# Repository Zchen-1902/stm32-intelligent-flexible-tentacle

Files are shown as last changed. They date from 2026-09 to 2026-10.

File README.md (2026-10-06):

# 基于示教学习的多触手智能柔性末端执行器

本项目面向柔性抓取与仿生作业场景，采用 STM32H743 作为主控制器、STM32G474 作为三电机 FOC 从控制器，集成 VL53L8CH ToF 感知、端侧 CNN/TCN 推理、CAN/FDCAN 通信、上位机控制与示教数据采集功能。

## 目录结构

```text
firmware/
  g4-motor-controller/   STM32G474 三电机 FOC 控制工程
  h7-main-controller/    STM32H743 感知、推理和多触手控制工程
pc/
  tentacle-controller/   多触手运动控制上位机
  act-data-collector/    ACT 示教数据采集上位机
training/
  gesture-cnn/           手势识别 CNN 训练代码
  act-tcn/               ACT/TCN 策略训练与 ONNX 导出代码
models/                  最终部署模型
hardware/                嘉立创 EDA 专业版 PCB 工程
docs/                    项目文档
```

## 主要功能

- STM32H743 完成 ToF 数据采集、模型推理、控制调度和状态管理。
- STM32G474 完成三台无刷电机的编码器读取、FOC 控制和安全保护。
- 主从控制器通过 CAN/FDCAN 交换目标位置与电机状态。
- 上位机支持单触手、双触手和四触手控制，以及运行状态可视化。
- ACT 数据采集工具同步保存 ToF 帧和三电机位置，用于示教策略训练。
- 端侧部署手势 CNN 与 Delta-TCN 两套模型。

## 工程入口

### G4 电机控制器

- CubeMX：`firmware/g4-motor-controller/FOC_G474VET6_CONFIG.ioc`
- Keil：`firmware/g4-motor-controller/MDK-ARM/FOC_G474VET6_CONFIG.uvprojx`

### H7 主控制器

- CubeMX：`firmware/h7-main-controller/H743VIT6.ioc`
- Keil：`firmware/h7-main-controller/MDK-ARM/H743VIT6.uvprojx`

### 上位机与训练代码

各 Python 子工程中的 `README.md`、`requirements.txt` 和入口脚本给出了对应的运行方式。训练数据、编译中间文件和本地缓存未纳入仓库。

### PCB 硬件设计

- 总览：[`hardware/README.md`](hardware/README.md)
- H7 主控板：`hardware/H7主控板/h743vit6.eprj2`
- 编码器板与 SPI 转接板：`hardware/编码器板与SPI转接板/编码器.eprj2`
- 三电机驱动板与电源板：`hardware/驱动板与电源板/FOC无刷驱动板.eprj2`

上述文件使用嘉立创 EDA 专业版打开。生产前需要重新执行原理图检查、PCB DRC，并核对层叠、器件封装、电源额定值和当前物料可用性。

### 开发日志

- [`docs/PROJECT_ENGINEERING_LOG.md`](docs/PROJECT_ENGINEERING_LOG.md)：从工程初始化、FOC 调试到 ACT 模型部署和 GitHub 发布的完整开发记录。

## 模型

- `models/gesture_openness_cnn.onnx`：手势开合识别模型。
- `models/delta_tcn_scene6_epoch010.onnx`：单触手示教策略模型。

## 说明

仓库保留可复现工程所需的源码、配置和最终模型，未收录 Keil 编译产物、第三方桌面工具、训练数据集及本地临时文件。

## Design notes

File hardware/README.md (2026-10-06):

# PCB 硬件设计

本目录保存多触手智能柔性末端执行器的三套 PCB 工程源文件。工程采用嘉立创 EDA 专业版 `.eprj2` 格式，保留原理图、PCB、工程结构及元件信息。

## 文件结构

| 目录 | 工程文件 | 主要用途 |
|---|---|---|
| `H7主控板` | `h743vit6.eprj2` | STM32H743 上层主控、感知、通信、存储和端侧模型部署 |
| `编码器板与SPI转接板` | `编码器.eprj2` | 磁编码器安装及多路 SPI 信号转接 |
| `驱动板与电源板` | `FOC无刷驱动板.eprj2` | STM32G474 三电机 FOC、栅极驱动、电流采样及系统供电相关电路 |

各子目录仅保存最终 PCB 工程文件，不包含嘉立创 EDA 自动生成的 `_backup` 历史压缩包。

## 打开方式

1. 安装嘉立创 EDA 专业版。
2. 在软件中打开或导入对应的 `.eprj2` 工程文件。
3. 检查工程中的原理图、PCB 页面、封装和网络连接。
4. 如需生产，重新生成当前版本的 Gerber、钻孔、坐标和 BOM 文件。

## 使用注意

- PCB 工程记录的是本项目样机所用硬件版本，不代表未经检查即可直接批量生产。
- 下单前应重新执行 ERC/DRC，并核对板层、铜厚、过孔、电源线宽和高电流回路。
- 应根据当前采购器件重新检查封装、替代料和 BOM，不直接沿用历史物料状态。
- 烧录或上电前应核对板卡版本与固件中的引脚、CAN 节点及板级参数配置。
- 历史自动备份仍保留在本地材料目录，未纳入公开仓库。

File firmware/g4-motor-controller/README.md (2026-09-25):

# STM32G474 三电机 FOC 控制工程

这是从 `D:\STM32Cube_project\4.8` 整理出的独立 G4 控制板工程。目录内包含完整源码、STM32 HAL/CMSIS、CMSIS-DSP 数学库、CubeMX 配置和 Keil MDK 工程。

## 打开和编译

1. 使用 Keil MDK 打开 `MDK-ARM/FOC_G474VET6_CONFIG.uvprojx`。
2. 选择工程目标 `FOC_G474VET6_CONFIG` 后执行 Build。
3. 如需修改引脚、时钟或外设，使用 STM32CubeMX 打开 `FOC_G474VET6_CONFIG.ioc`。

## 构建验证

本独立副本已使用 Keil MDK 5.40、Arm Compiler 5.06 update 6 完成一次全量构建：

```text
0 Error(s), 11 Warning(s)
Code=49034, RO-data=2830, RW-data=228, ZI-data=6660
```

可直接烧录的 `hex`、调试用 `axf` 和链接映射 `map` 已复制到 `Release/`。构建警告来自当前业务源码中的未使用调试变量、未引用备用函数和浮点类型提升，不是独立工程缺少文件造成的。

## 当前关键配置

- MCU：STM32G474VET6
- 当前板配置：`G4_BOARD_PROFILE_ID = 4U`
- 当前 CAN 板号：`CAN_APP_BOARD_ID = 3U`
- PWM/电流环目标频率：10 kHz

烧录其他 G4 板之前，应在 `Core/motor/Config.h` 中选择对应的 `G4_BOARD_PROFILE_ID`。各板的 CAN ID、电机反馈方向和电角度补偿集中定义在 `Core/motor/board_profiles.h`。

## 主要模块

- `Core/motor`：三环控制、FOC、SVPWM和板级参数
- `Core/adc_app`：三电机相电流采样
- `Core/spi_encoder`：三路磁编码器读取
- `Core/drv8323S_drive`：三路栅极驱动器配置
- `Core/can_app`：与 H7 主控的 CAN FD 通信
- `Core/Vofa_debug`：VOFA JustFloat 调试输出
- `Core/timer_app`：低频定时任务

`Core`、`Drivers`、`Middlewares` 和 `MDK-ARM` 的相对目录关系不能改变，否则 Keil 工程中的相对路径将失效。

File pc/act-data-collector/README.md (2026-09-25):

# Flexible Tentacle ACT

单触手ACT示教控制与Episode采集上位机。

当前已完成USART1单触手控制与ACT Episode采集链路：

- 固定三列主界面。
- 真实COM枚举与自动重连，默认 `2000000, 8N1`。
- 串口工作线程、拔出销毁和自动重连。
- ASCII `ACT PING/SELECT/STATUS/ENABLE/MOVE/HOME/STOP/CAPTURE`发送。
- `0xA55A`二进制ACK/STATUS/ERROR/FRAME流式解析。
- 只有PING ACK和STATUS均有效才显示H7已同步。
- 4198字节ACT_FRAME解析、ToF热力图和实际姿态降频显示。
- Episode内存缓存、序号缺口与质量统计、后台原子保存和退出恢复。
- 支持任意时长Episode，并在保存时自动检查训练字段、尺寸及有效窗口数量。
- 采集期间暂停常规STATUS轮询，避免占用H7帧发送时隙。

运行：

```powershell
cd F:\act_vla\flexible_tentacle_act\pc_collector
python main.py
```

测试：

```powershell
cd F:\act_vla\flexible_tentacle_act
python -m unittest discover -s tests -v
```

依赖：

```powershell
python -m pip install -r pc_collector\requirements.txt
```

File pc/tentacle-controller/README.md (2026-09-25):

# 四触手控制台原型

这是独立的Windows桌面原型，不修改H7/G4固件。

## 运行

使用现有设计工具虚拟环境：

```powershell
E:\sobot\Open-Spiral-Robots-main\design-tool\.venv\Scripts\python.exe PC_Tentacle_Controller\main.py
```

默认启动模拟模式。打开真实串口后才会发送串口数据。

## 当前原型范围

- 四触手2x2工作区和缩小窗口布局基础。
- 纯Qt轻量伪三维姿态显示，无需MuJoCo和OpenGL。
- VOFA JSON命令导入和分组按钮。
- 每条命令独立保存上一次输入内容。
- 串口配置、ASCII/HEX、CRLF和可展开接收窗口。
- 参数锁定、当前对象高亮、回正、模式和模拟响应。

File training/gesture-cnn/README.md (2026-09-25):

# H743 VL53L8CH 张握程度训练说明

本目录用于电脑端训练手掌张握程度模型。目标是把采集到的 `gesture.csv` 转换成一个可交给 STM32Cube.AI 的 ONNX 模型。

## 训练目标

输入一帧 VL53L8CH 数据：

```text
distance[64] + CNH[64][8] = 576 维
```

输出一个连续数值：

```text
openness_score = 0~100
0   表示完全握拳
100 表示完全张开
```

注意：这不是分类模型。即使采集标签是 `0/25/50/75/100`，模型输出仍然可以是 `37、62、88` 这样的连续值。

## CSV 字段要求

当前 MCU 采集的 CSV 应包含 709 列：

```text
timestamp_ms,label_score,frame_count,mode,valid,
d0...d63,
target_status_z0...target_status_z63,
nb_target_z0...nb_target_z63,
cnh_z0_b0...cnh_z63_b7
```

训练脚本第一版只把下面 576 维作为模型输入：

```text
d0...d63
cnh_z0_b0...cnh_z63_b7
```

下面两组字段暂时只用于清洗数据，不直接喂给模型：

```text
target_status_z0...target_status_z63
nb_target_z0...nb_target_z63
```

## 标签规则

参与回归训练的标签：

```text
0~100
```

不参与回归训练的标签：

```text
255 = 无手/无效
```

无手数据后续可以单独训练“有手/无手”判断。第一版先把张握程度回归模型训稳定。

## 依赖

电脑端需要 Python 环境，并安装：

```bash
pip install numpy torch
```

如果 `torch.onnx.export` 报 ONNX 相关错误，再安装：

```bash
pip install onnx
```

## 训练命令

在工程根目录 `D:/STM32Cube_project/4.8` 下运行：

```bash
python H743VIT6/Training/train_openness.py --csv G:/gesture.csv --epochs 300
```

也可以指定输出目录：

```bash
python H743VIT6/Training/train_openness.py --csv G:/gesture.csv --out H743VIT6/Training/exported --epochs 300
```

## 模型大小选择

默认模型：

```text
576 -> 32 -> 16 -> 1
```

如果验证误差偏大，可以试更大的隐藏层：

```bash
python H743VIT6/Training/train_openness.py --csv G:/gesture.csv --hidden 64 32 --epochs 300
```

## CNN 训练版本

如果 MLP 在不同距离或手臂干扰下误差偏大，可以使用 CNN 版本。CNN 输入为固定特征图：

```text
20 x 8 x 8
```

其中包含相对距离、有效点mask、前景mask、target_status、nb_target、8个CNH bin，以及复制到全图的中心位置/距离/前景框统计特征。CNN 前景参数和当前 MCU 侧保持一致：

```text
有效距离：160~450mm
前景区域：d_min + 120mm
```

训练命令：

```bash
python H743VIT6/Training/train_openness_cnn.py --csv H743VIT6/Training/data/gesture_z220_400_plus50_clean_abs40.csv --out H743VIT6/Training/exported_cnn --epochs 300
```

输出文件：

```text
gesture_openness_cnn.onnx   给 STM32Cube.AI 转换使用
gesture_openness_cnn.pt     PyTorch checkpoint
cnn_norm_params.json        20个通道的归一化参数
cnn_train_report.json       训练报告
```

## 数据清洗逻辑

脚本默认保留：

```text
valid == 1
label_score 在 0~100
有效 zone 数量 >= 3
```

有效 zone 的判断：

```text
target_status == 5 或 9
nb_target_detected > 0
```

如果只是想先验证训练脚本能跑，可以临时关闭质量过滤：

```bash
python H743VIT6/Training/train_openness.py --csv G:/gesture.csv --no-quality-filter
```

## 输出文件

训练完成后输出到 `H743VIT6/Training/exported/`：

```text
gesture_openness.onnx   给 STM32Cube.AI 转换使用
gesture_openness.pt     PyTorch checkpoint，方便复现
norm_params.json        输入归一化参数，MCU 推理前必须使用同一套参数
train_report.json       训练样本数、标签分布、误差指标
```

## 评价指标

脚本会打印：

```text
MAE
RMSE
最大误差
```

这里的误差单位就是 `0~100` 分数。

第一版建议目标：

```text
MAE <= 8~10：可用
MAE <= 5：较好
```

如果 MAE 很大，优先检查数据质量，而不是先加大模型。

## 后续接入 CubeAI

部署时需要保持同样的数据顺序：

```text
d0...d63
cnh_z0_b0...cnh_z63_b7
```

并使用 `norm_params.json` 中的参数做同样归一化：

```text
x_norm = (x - mean) / std
```

CubeAI 推理输出是 `0~1`，最终再转换为：

```text
openness_score = output * 100
```

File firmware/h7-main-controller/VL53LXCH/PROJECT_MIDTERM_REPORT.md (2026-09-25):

# STM32G474 三电机控制项目中期记录

## 1. 项目目标

本项目基于 STM32G474VET6，目标是驱动 3 个 BM352006 无刷电机，用于带减速器和线轮的拉索式机构。当前阶段主要任务是搭建三电机控制的软件基础框架，在功率板和部分传感器未完全焊接前，优先完成可独立验证的软件模块、调试链路和控制算法基础。

当前项目暂不以直接带载运行电机为目标，而是先保证：

- 软件结构清晰，后续三电机扩展方便。
- VOFA 调试链路稳定，能够观察关键变量。
- 定时器、ADC、SPI、DMA 等底层链路逐步独立验证。
- FOC 数学计算和 PWM CCR 写入逻辑先在无功率输出条件下验证。
- 编码器、DRV、电流采样等硬件相关模块先搭建接口，等待硬件具备条件后实测。

## 2. 当前硬件资源规划

主要硬件资源分配如下：

- `TIM1`：电机 1 三相互补 PWM。
- `TIM8`：电机 2 三相互补 PWM。
- `TIM20`：电机 3 三相互补 PWM。
- `ADC1`：电机 1 三相电流采样。
- `ADC3`：电机 2 三相电流采样。
- `ADC4`：电机 3 三相电流采样。
- `ADC2`：温度采样。
- `SPI1`：三路 DRV8323S/DRV8328 驱动器配置。
- `SPI3`：三路 MT6816 磁编码器读取。
- `USART1`：VOFA JustFloat 调试输出。
- `FDCAN1`：后续与上位主控通信。
- `TIM4`：5ms 系统软件调度基础节拍。
- `TIM7`：当前设置为 10ms 编码器采样/速度计算节拍。
- `TIM6`：预留给 ADC2 温度采样节拍。

## 3. 当前软件目录结构

当前新增或重点维护的软件模块如下：

- `Core/Vofa_debug`：VOFA JustFloat 调试输出模块，使用 USART1 DMA 发送浮点数据。
- `Core/timer_app`：定时器应用层，将 TIM4/TIM6/TIM7 中断转换为主循环可处理的软件任务标志。
- `Core/adc_app`：ADC DMA 数据组织与回调入口，负责三路电机电流 ADC 的原始采样缓存。
- `Core/spi_encoder`：MT6816 SPI 编码器驱动，已实现 SPI3 DMA 串行读取三路编码器的框架。
- `Core/drv8323S_drive`：DRV 驱动配置接口框架，目前以头文件和基础结构为主。
- `Core/motor/foc_drive.c/.h`：FOC 数学与 SVPWM 输出通路，包含 Clarke/Park/InvPark/SVPWM 和 CCR 写入。
- `Core/motor/Config.h`：当前阶段主要配置参数，包括电机、编码器、PID 默认参数、限幅和调试相关配置。
- `Core/motor/Motor_type.h`：电机相关结构体类型定义。

## 4. 当前已完成内容

### 4.1 VOFA 调试链路

USART1 + DMA 的 VOFA JustFloat 调试链路已经跑通，可以稳定显示波形。当前默认调试主题仍以 `VOFA_TOPIC_FOC_TEST` 为主，用于显示 FOC/SVPWM 测试数据和 CCR 输出。

当前 FOC 测试主题主要通道为：

- `I0`：测试电角度。
- `I1`：实际电角度预留。
- `I2`：SVPWM 扇区。
- `I3`：d 轴归一化电压。
- `I4`：q 轴归一化电压。
- `I5`：TIM1 CCR1。
- `I6`：TIM1 CCR2。
- `I7`：TIM1 CCR3。

### 4.2 定时任务框架

`timer_app` 已经建立：

- `TIM4` 当前作为 5ms 基础调度节拍。
- `TIM7` 当前作为编码器采样/速度计算节拍。
- 中断中只置任务标志，具体任务在主循环中执行，避免中断负担过重。

当前 `TIM7` 的 CubeMX 公式为：

```c
htim7.Init.Period = 100000 / SPEED_CALCU_FREQ - 1;
```

当前 `Config.h` 中：

```c
#define SPEED_CALCU_FREQ 10
```

因此当前 TIM7 实际周期为 10ms。

### 4.3 ADC DMA 框架

`adc_app` 已建立，用于组织 `ADC1`、`ADC3`、`ADC4` 的原始采样数据和 DMA 完成标志。当前阶段 ADC 真实电流输入尚未完整接入，因此只能验证 ADC/DMA 链路，暂不能验证实际电流值、零漂、电流方向和比例系数。

当前适合验证：

- ADC DMA 是否启动。
- DMA 完成回调是否进入。
- raw buffer 是否更新。

当前不适合验证：

- 三相电流换算是否准确。
- 零漂校准是否真实有效。
- DRV 电流采样输出比例是否正确。

### 4.4 FOC/SVPWM 输出通路

`foc_drive` 已实现第一版 FOC 输出通路：

- `FOC_Clarke()`：三相电流到 alpha/beta。
- `FOC_Park()`：alpha/beta 到 d/q。
- `FOC_InvPark()`：d/q 电压到 alpha/beta。
- `FOC_SVPWM()`：alpha/beta 归一化电压到 SVPWM duty。
- `FOC_WritePwmDuty()`：将 duty 写入 TIM CCR。
- `FOC_RunVoltageNorm()`：执行一次归一化电压 FOC 计算。

当前已通过 VOFA 验证：

- 测试电角度可以周期扫描。
- SVPWM sector 可以 1~6 循环。
- CCR1/CCR2/CCR3 会随 duty 变化。
- 当前只写 CCR，不启动 PWM 输出，不控制 DRV，不接功率板。

需要注意：当前 `VOFA_TOPIC_FOC_TEST` 显示的 `sector` 是 SVPWM 输入电压矢量 `Ualpha/Ubeta` 所在扇区，不一定等于转子电角度所在扇区。当测试参数为 `vd=0, vq>0` 时，电压矢量相对电角度有 90 度偏移。

### 4.5 SPI 编码器 DMA 框架

`spi_encoder` 已实现三路 MT6816 编码器读取框架：

- SPI3 配置为 8bit、Mode 3、MSB first。
- 使用 DMA Normal 模式。
- 三路编码器通过 CSN1/CSN2/CSN3 串行读取。
- 每次 TIM7 任务触发后，在主循环启动一次三路编码器 DMA 读取。
- SPI DMA 完成后通过 `HAL_SPI_TxRxCpltCallback()` 转发到 `SPI_Encoder_TxRxCpltCallback()`。
- 三路 raw 读取完成后统一更新角度、速度、多圈计数。

当前编码器数据流为：

```text
TIM7 10ms节拍
-> main启动 SPI_Encoder_Start_Update_All_DMA()
-> SPI3 DMA依次读取 encoder1/encoder2/encoder3
-> 解析MT6816 raw
-> raw转机械角
-> 处理零点和方向
-> 更新单圈角、多圈角、turn_count、speed
```

MT6816 手册已核对：

- `0x03 = Angle[13:6]`
- `0x04[7:2] = Angle[5:0]`
- `0x04[1] = No_Mag_Warning`
- `0x04[0] = PC 偶校验位`

当前尚未接真实编码器实测，因此 raw 连续性、方向、零点、多圈和速度仍需后续硬件验证。

### 4.6 DRV 驱动框架

`drv8323S_drive` 已建立基础文件，当前主要完成驱动配置接口的规划和头文件框架。SPI1 使用 8bit 两字节方式更适合当前 HAL 配置，第一版不使用 SPI1 DMA。

后续需要补充：

- DRV 寄存器读写。
- DRV 基础初始化。
- CAL 引脚校准函数。
- 关键寄存器配置。
- nFAULT/状态寄存器读取。

## 5. 当前主循环与中断关系

当前核心回调链路如下：

```text
TIM4中断
-> HAL_TIM_PeriodElapsedCallback()
-> Timer_App_PeriodElapsedCallback()
-> TIMER_APP_TASK_5MS
-> main中调用 VOFA_Debug_Task()

TIM7中断
-> HAL_TIM_PeriodElapsedCallback()
-> Timer_App_PeriodElapsedCallback()
-> TIMER_APP_TASK_SPEED_CALC
-> main中调用 SPI_Encoder_Start_Update_All_DMA()

SPI3 DMA完成
-> HAL_SPI_TxRxCpltCallback()
-> SPI_Encoder_TxRxCpltCallback()

SPI3错误
-> HAL_SPI_ErrorCallback()
-> SPI_Encoder_ErrorCallback()

ADC DMA完成
-> HAL_ADC_ConvCpltCallback()
-> ADC_App_ConvCpltCallback()

USART1 DMA发送完成
-> HAL_UART_TxCpltCallback()
-> VOFA_Debug_TxCpltCallback()
```

当前设计原则是：中断中只做短任务或回调转发，复杂处理尽量放在主循环或模块内部的低频任务中。

## 6. 当前未验证项与风险点

当前项目仍有以下未验证项：

- 编码器硬件尚未焊接，MT6816 SPI 数据读取未实物验证。
- 编码器速度计算当前使用固定软件时间戳，后续可升级为基于真实 DMA 完成时间戳的每路更新时间。
- ADC 电流采样链路未接真实电流采样前端，无法验证实际电流换算。
- DRV8323S 配置和 CAL 校准函数尚未完整实现。
- TIM1/TIM8/TIM20 触发 ADC 的实际采样时序需要后续结合硬件和 ADC 数据确认。
- FOC 当前只验证数学输出和 CCR 写入，没有启动真实 PWM 输出。
- PWM 互补输出、死区、DRV 使能、功率级保护尚未联调。
- FDCAN 上位机协议尚未实现。
- PID 三环控制算法尚未开始正式编码。

## 7. Git 记录

当前已建立 Git 仓库，并已整理 `.gitignore`，Keil 编译产物不再纳入版本控制。

近期关键提交：

- `1202a47`：initial project snapshot
- `5727d52`：2026-04-09 initial project snapshot
- `1ea4329`：2026-04-11 vofa working and key exti falling edge update
- `6f2a58d`：add timer app 5ms scheduler
- `38f559f`：add adc app and foc vofa validation
- `879bfc7`：Add SPI encoder DMA and driver framework
- `ce05f83`：Ignore Keil build outputs
- `aaa3b3e`：Set TIM7 encoder task period to 10ms

当前重要快照：

```text
snapshot-before-tim7-encoder-dma
```

## 8. 后续开发计划

近期建议开发顺序如下：

1. 完成 `VOFA_TOPIC_ENCODER` 的实际数据填充，并支持选择查看某一路编码器。
2. 在不接硬件的情况下继续验证 `VOFA_TOPIC_FOC_TEST` 和 CCR 输出是否稳定。
3. 开始编写控制算法层模块，包括 PID、限幅、积分限幅、抗积分饱和、死区、斜坡和滤波。
4. 建立单电机 `motor_core` 软件链路，先使用假数据验证数据流。
5. 建立最小单电机状态机，包括 OFF、INIT、CALIB、READY、RUN、FAULT。
6. 硬件焊接完成后，依次实测编码器、ADC电流采样、DRV配置和PWM输出。
7. 先完成单电机开环，再进入电流环闭环。
8. 单电机链路稳定后，再扩展到三电机统一调度。

## 9. 当前建议

在硬件尚未完整具备条件前，当前最适合继续推进的软件内容是控制算法层：

- `control_pid`
- `control_ramp`
- `control_deadband`
- `control_limit`
- `control_filter`

这些模块不依赖真实硬件，可以通过假输入和 VOFA 波形验证。完成后再接入单电机 `motor_core`，为后续真实闭环控制打基础。

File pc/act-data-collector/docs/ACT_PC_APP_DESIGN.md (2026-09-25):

# 柔性触手 ACT 采集上位机设计方案

## 1. 目标与边界

本上位机专门用于单触手 ACT 示教控制、数据采集、Episode 保存和通信诊断，不替代现有四触手控制上位机。

两个串口职责固定：

```text
UART7：原有 VOFA/四触手控制
USART1：ACT 单触手控制与采样数据
```

第一版目标是稳定采集完整 Episode。训练和推理不放入上位机主界面，也不同时控制多条触手。

## 2. 工程路径

```text
F:\act_vla\flexible_tentacle_act
├─ pc_collector
│  ├─ main.py
│  ├─ app.py
│  ├─ serial_service.py
│  ├─ protocol.py
│  ├─ episode_buffer.py
│  ├─ tentacle_view.py
│  ├─ tof_heatmap.py
│  └─ requirements.txt
├─ datasets
│  ├─ raw
│  └─ processed
├─ training
│  ├─ build_dataset.py
│  ├─ train_act.py
│  ├─ evaluate_act.py
│  └─ export_onnx.py
├─ models
│  ├─ checkpoints
│  └─ exported
├─ configs
├─ docs
│  └─ ACT_PC_APP_DESIGN.md
└─ README.md
```

ACT 固件工程：

```text
D:\STM32Cube_project\4.8\H743VIT6_ACT
```

## 3. 与原上位机的关系

参考工程：

```text
D:\STM32Cube_project\4.8\PC_Tentacle_Controller
```

可以复用：

| 原模块 | 复用内容 | ACT 上位机调整 |
|---|---|---|
| `main.py` | PySide6 入口和样式 | 启动 ACT 采集窗口 |
| `serial_service.py` | COM 枚举、连接和重连 | USART1 文本发送、二进制接收 |
| `tentacle_view.py` | 触手姿态绘制 | 只显示当前单触手 |
| `app.py` | 控件样式和布局 | 改为单触手示教与采集流程 |

不复用四触手模式、`SNAP?/POS?` 轮询、VOFA 命令组、按键模式和 PC/AI 控制源页面。

## 4. 通信总体结构

通信采用简单的混合方式：

```text
PC -> H7：以换行结束的 ASCII 文本命令
H7 -> PC：带长度和 CRC32 的二进制数据包
```

这样做的原因：

- H7 接收命令容易调试，不需要复杂的二进制命令解析器。
- H7 返回的状态和 ACT_FRAME 数据量较大，二进制传输更高效。
- UART7 与 USART1 完全分开，不会混入 VOFA 文本。

## 5. 当前已经实现的第一阶段协议

### 5.1 当前命令

```text
ACT PING
ACT SELECT 1
ACT SELECT 2
ACT SELECT 3
ACT SELECT 4
ACT STATUS
```

每条命令必须以 `\n` 或 `\r\n` 结束。当前 H7 已实现单触手控制、采集控制和 ACT_FRAME 输出。

### 5.2 H7 二进制包格式

```text
magic        uint16   固定 0xA55A
type         uint8    数据包类型
version      uint8    当前为 1
data_length  uint16   有效数据字节数
data         uint8[]  有效数据
crc32        uint32   对前面全部字节计算的 CRC32
```

多字节字段均使用小端顺序。CRC32 参数：

```text
初值：0xFFFFFFFF
反射多项式：0xEDB88320
最终异或：0xFFFFFFFF
```

当前包类型：

```text
1：ACK
2：STATUS
3：ERROR
4：FRAME
```

### 5.3 ACK 与 ERROR 数据

```text
data[0]：command_id
data[1]：result
```

命令编号：

```text
0：UNKNOWN
1：PING
2：SELECT
3：STATUS
4：ENABLE
5：MOVE
6：HOME
7：STOP
8：CAPTURE
```

结果编号：

```text
0：成功
1：命令格式错误
2：参数错误
```

`ACT STATUS` 直接返回 STATUS 包，不再额外返回 ACK。

### 5.4 STATUS 数据

```text
selected_tentacle   uint8
control_enabled     uint8
capture_state       uint8
reserved            uint8
sent_frame_count    uint32
dropped_frame_count uint32
```

这些字段均由当前固件实时更新；`sent_frame_count` 和 `dropped_frame_count` 在一次新采集开始时清零。

### 5.5 当前请求处理规则

当前 H7 只有一个小型 TX DMA 缓冲区，因此上位机必须：

1. 发送一条状态命令。
2. 等待完整响应并校验 CRC32。
3. 收到响应或超时后，再发送下一条状态命令。

当前不设置通用命令序号，也不能连续堆积多条状态命令。ACT_FRAME 使用 VL53 的全局 `frame_seq` 检测采样丢帧。

## 6. 后续控制命令

在第一阶段通信验证通过后，按以下形式扩展：

```text
ACT ENABLE 1
ACT ENABLE 0
ACT MOVE x y bend stiff
ACT HOME
ACT STOP
ACT CAPTURE 1
ACT CAPTURE 0
ACT STATUS
```

处理规则：

- `ENABLE/SELECT/HOME/STOP/CAPTURE` 是状态命令，每次执行只返回一次 ACK 或 ERROR。
- `MOVE` 最高 20 Hz，只保留最新目标，不排队旧目标，也不为每一帧返回 ACK。
- `STOP` 始终具有最高控制优先级。
- `CAPTURE 1` 只开启 ACT_FRAME 数据流，不自动启动电机。
- `CAPTURE 0` 只停止 ACT_FRAME 数据流，不自动停止电机。

## 7. 上位机功能

### 7.1 串口连接

界面显示：

```text
COM 口选择与刷新
连接/断开
协议同步状态
RX/TX 字节数
CRC 错误数
frame_seq 丢帧数
H7 丢帧计数
```

USART1 当前固定使用 `2 Mbps, 8N1`；上位机将其设为默认值，其他波特率只用于明确的旧版小包调试。

连接后依次发送：

```text
ACT PING
ACT STATUS
```

只有收到合法响应后才显示“H7 已同步”。打开 COM 成功不代表协议已经同步。

### 7.2 单触手选择与控制

选择范围为触手 1～4。切换触手时必须处于未采样、未启用控制的状态。

示教参数沿用 H7 单触手映射语义：

```text
X：-100～100
Y：-100～100
Bend：0～100
Stiff：0～100
```

界面高频变化只更新本地“最新目标”。串口发送定时器最多以 20 Hz 发送一次最新 `ACT MOVE`，不能累计历史目标。

### 7.3 姿态和热力图

触手视图显示当前触手编号、方向、弯曲程度和 `actual_q[3]`。

8×8 热力图用于检查瓶子位置、无效像素和触手遮挡。热力图可以按 5～10 Hz 降频刷新，但原始 ACT_FRAME 必须完整进入 EpisodeBuffer。

## 8. 一帧 ACT 原始数据

H7 每产生一帧数据，就把同一采样时刻附近的 ToF 数据和电机实际位置放进同一个 ACT_FRAME：

```text
frame_seq                  VL53 全局有效帧编号
timestamp_ms               ToF 帧读取完成时间
tentacle                   当前示教触手编号

distance_mm[64]            8×8 距离
target_status[64]          测距状态码
target_count[64]           每个区域检测到的目标数量
signal[64]                 目标回波强度
ambient[64]                环境红外强度
reflectance[64]            反射率
sigma_mm[64]               距离不确定度
cnh_hist[64][10]           10 个固定距离区间的 CNH 直方图
cnh_scaler[64][10]         对应 CNH 缩放参数

actual_q[3]                当前三台电机相对 HOME 的实际位置
action_q[3]                最近成功进入 CAN 队列的三电机目标
valid_flags                actual/action有效位及FAULT位
status_age_ms              最近CAN状态年龄
```

坐标语义统一为：

```text
正数：收线
负数：放线
1 q：0.01 rad 电机机械角
```

`frame_seq` 不随 `ACT CAPTURE 1` 清零。上位机以本次采集首帧为基准记录缺口，不能假设编号从 1 开始。

上位机原样保存当前固件提供的 `actual_q`、`action_q`、`valid_flags` 和 `status_age_ms`。不由上位机伪造不存在的 `motor_rx_seq` 或 `motor_tick_ms`。

## 9. Episode 采集与保存

采集状态：

```text
空闲 -> 开始采样 -> 采样中 -> 停止采样 -> 等待保存
等待保存 -> 保存 Episode -> 空闲
等待保存 -> 删除 Episode -> 空闲
```

采样期间：

- 上位机逐帧接收并校验 ACT_FRAME。
- 合法帧立即追加到内存 Episode。
- 不为每一帧创建文件，也不在采样期间写正式数据集。
- `sample_seq` 发生跳变时记录缺口，后续不得跨缺口构造训练样本。

用户确认保存后一次性生成：

```text
datasets\raw\episode_000001
├─ meta.json
└─ raw_data.npz
```

`raw_data.npz` 数组：

```text
frame_seq        [N]
timestamp_ms     [N]
pc_receive_ns    [N]
tentacle         [N]
distance_mm      [N,64]
target_status    [N,64]
target_count     [N,64]
signal_per_spad  [N,64]
ambient_per_spad [N,64]
reflectance      [N,64]
range_sigma_mm   [N,64]
cnh_raw          [N,10,64]
cnh_scaler       [N,10,64]
actual_q         [N,3]
action_q         [N,3]
valid_flags      [N]
status_age_ms    [N]
```

保存在线程中执行，先写临时文件，全部成功后再改为正式名称。删除操作只清空尚未保存的内存 Episode。

`N` 是本次实际收到的完整帧数，不固定。固定的只是单个 ACT_FRAME 数据布局；
采集可由用户在任意时刻停止，所有数组第一维随 Episode 时长变化。保存时同时在
`meta.json.training_compatibility` 写入字段/尺寸校验结果和有效训练窗口数量。

## 10. 训练数据构造

### 10.1 单帧模型输入

对 Episode 中第 `k` 帧构造：

```text
tof[k]    [18,8,8]
actual[k] [3]
```

18 个 ToF 通道：

```text
0       distance
1       valid_mask
2       status_ok
3       target_count
4       signal
5       ambient
6       reflectance
7       sigma
8～17   CNH bin 0～9
```

`valid_mask` 和 `status_ok` 在离线预处理中根据原始距离、状态码和设定范围计算。CNH 使用固定的 10 个距离区间，不为每个 Episode 单独采集背景，也不把背景图作为额外模型输入。

模型输入不包含过去 12 帧，也不包含操作者目标命令。当前电机位置 `actual[k]` 用来告诉模型触手此刻已经运动到哪里。

### 10.2 监督标签

第 `k` 帧的标签是后续 12 帧真实电机位置：

```text
future_actual[k] = actual[k+1], ..., actual[k+12]
shape = [12,3]
```

采样频率为 20 Hz 时，标签覆盖未来约 0.6 秒。标签来自示教过程中真实记录的后续位置，不是当前控制命令。

以下位置不能构造样本：

- `sample_seq` 缺口两侧跨越的位置。
- Episode 末尾不足 12 个未来帧的位置。
- ToF 与电机时间差超过最终设定阈值的位置。

## 11. 上位机模块职责

### `serial_service.py`

负责 COM 枚举、连接、断开、原始字节接收和文本命令发送，不解析业务数据。

### `protocol.py`

负责生成带换行的 ACT 文本命令，以及对 H7 二进制字节流执行：

```text
查找 magic
读取固定包头
等待完整 data_length
检查 version 和长度
校验 CRC32
输出完整消息
错误后重新寻找下一个 magic
```

一次 `readyRead` 可能只有半包，也可能包含多个包，不能假设一次回调等于一个数据包。

### `episode_buffer.py`

负责内存 Episode、`frame_seq` 连续性、保存和删除，不直接操作串口或电机。

### `app.py`

负责界面状态转换和按钮使能，不直接解析协议，也不直接写 NPZ。

### `tentacle_view.py` 与上位机热力图控件

只负责降频显示，不能修改或丢弃 EpisodeBuffer 中的原始数据。

## 12. H7 完整数据流需要的发送结构

当前 H7 使用一个大 ACT_FRAME DMA 缓冲区和小包等待槽：

```text
一个大 ACT_FRAME 缓冲区（忙时保留最新传感器帧并累计跳过数量）
一个小型 ACK/STATUS/ERROR 等待槽
一个函数统一拥有 HAL_UART_Transmit_DMA
```

发送原则：

- 正在发送的缓冲区绝不允许被覆盖。
- 下一帧缓冲区已占用时，丢弃整帧并增加 `dropped_frame_count`。
- 不能发送半帧，也不能阻塞 CAN、VL53 或电机任务等待串口。
- 当前大帧发送完成后，优先发送等待中的 ACK/ERROR。
- TX 缓冲区按 32 字节对齐，DMA 前清理 DCache。
- RX 循环 DMA 缓冲区按 32 字节对齐，CPU 读取前失效 DCache。

在 2 Mbps、8N1 下，理论有效字节率约 200 KB/s。约 4.2 KB 的 ACT_FRAME 以 20 Hz 发送约占 84 KB/s，带宽有余量。

## 13. 开发与验收顺序

### 第一阶段：通信底座

已完成 H7 端：

```text
USART1 循环 RX DMA
ACT PING
ACT SELECT 1～4
ACT STATUS
ACK/STATUS/ERROR 二进制包
CRC32
TX 超时和 UART 错误恢复
```

PC 最小串口测试和 1000 次分片 PING 解析回归已经完成。

### 第二阶段：单触手控制

接入 `ENABLE/MOVE/HOME/STOP`，验证方向、限幅和 STOP 行为与 UART7 的 SOLO 控制一致。

### 第三阶段：ACT_FRAME

USART1 使用 2 Mbps，接入20 Hz完整帧、电机/ToF对齐和EpisodeBuffer。连续采集15秒应得到约300帧。

### 第四阶段：数据保存与训练

上位机完成 `meta.json` 与 `raw_data.npz` 原始Episode保存；后续继续完成数据清洗、未来12帧标签构造、训练、评估和ONNX导出。

## 14. 第一版不做的功能

```text
四触手同时示教
串口7协议兼容层
SD卡ACT采集
每帧独立文件
上位机实时训练
上位机实时ACT推理
自动判断抓取成功
额外背景图输入
复杂三维重建
```

第一版只解决一件事：稳定控制一条触手，并可靠保存可用于 ACT 训练的完整 Episode。

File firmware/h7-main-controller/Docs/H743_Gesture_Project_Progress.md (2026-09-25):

# H743 手势识别采集项目进度文档

## 0. 文档状态说明

本文前半部分保留了项目早期推进记录，因此其中有些“当前未完成项”已经属于历史状态。`2026-07-05` 之前的复盘见第 12 章；之后的问题、解决过程和当前风险按时间顺序续写在第 13 章。

## 1. 任务目标

当前目标是把 `STM32H743VIT6` 开发板作为手势主控板使用，围绕 `VL53L8CH / VL53L8CH` ToF 传感器完成静态手部张握程度数据采集，并为后续训练、CubeAI 转换、量化部署和 CANFD 控制通讯做准备。

第一阶段的重点不是直接完成最终推理和控制，而是先稳定打通以下链路：

1. `VL53` 传感器初始化和 8x8 距离矩阵读取。
2. `CNH` 直方图特征输出和解析。
3. SD 卡 CSV 数据保存。
4. USART1 串口调试输出和 VOFA 命令控制。
5. LED 状态反馈。
6. 为后续训练数据打标签，最终得到 `0~100` 的手部张握程度回归值。

目标输出不是“识别具体手势类别”，而是输出一个连续或准连续的张握程度分数：

```text
0   = 接近握拳
25  = 偏握拳
50  = 半握/中间状态
75  = 偏张开
100 = 接近张开
255 = 无手/无效样本标签
```

后续希望通过 STM32CubeAI 将训练好的模型转换、量化并部署到 H743 上运行。

## 2. 当前总体方案

当前方案分为四层：

### 2.1 感知层

感知层由 `VL53_App` 负责，主要功能包括：

- 初始化 VL53 传感器。
- 配置 8x8 分辨率。
- 配置 CNH 输出。
- 每帧读取距离矩阵 `distance[64]`。
- 每帧读取 CNH 特征 `cnh[64][8]`。
- 对外提供采样请求接口。
- 在采样模式下将当前稳定帧保存到 SD 卡 CSV。

当前 CNH 参数为：

```c
#define VL53_APP_CNH_START_BIN   6
#define VL53_APP_CNH_NUM_BINS    8
#define VL53_APP_CNH_SUB_SAMPLE  1
```

含义：

- `START_BIN = 6`：从第 6 个距离 bin 开始取直方图。
- `NUM_BINS = 8`：每个 zone 保存 8 个 bin。
- `SUB_SAMPLE = 1`：不做额外降采样。

当前 CSV 特征规模：

```text
4 个基础字段 + 64 个距离值 + 64 * 8 个 CNH 值 = 580 列
```

当前 CSV 字段为：

```csv
timestamp_ms,frame_count,mode,valid,d0...d63,cnh_z0_b0...cnh_z63_b7
```

注意：当前 `label_score` 还没有正式写入 CSV，这是下一步必须补上的内容。

### 2.2 采集层

采集层现在仍由 `VL53_App` 内部完成具体写文件动作。

采样流程为：

1. 上层调用 `VL53_App_RequestSample()`。
2. VL53 模块记录当前请求时间。
3. 等待约 `500 ms`，让手部姿态稳定。
4. 将当前最新帧整理为 CSV 行。
5. 调用 `CsvLogger_AppendLine()` 写入 `0:/gesture.csv`。
6. 写入完成后通过 `VL53_App_ConsumeSampleResult()` 给上层返回结果。

当前 SD 写入策略：

- 每次采样都 `open -> write -> sync -> close`。
- 文件为空时自动写入 header。
- 每行写完后 `f_sync()`。
- 每次写完关闭文件，降低突然断电导致文件损坏的风险。

这样速度不是最高，但对当前人工采样和训练数据采集更稳。

### 2.3 VOFA 控制层

已经新增独立模块：

```text
H743VIT6/Core/Vofa_debug/vofa.h
H743VIT6/Core/Vofa_debug/vofa.c
```

VOFA 模块职责：

- 使用 USART1 DMA 环形缓冲接收字符串命令。
- 按 `\r` 或 `\n` 判断一条命令结束。
- 在主循环中解析命令，避免中断中做复杂操作。
- 控制采样模式、单次采样、连续采样和 LED 状态。
- 提供 `STATUS`、`HELP`、`ERRCLR` 等调试命令。

当前 USART1 作为 VOFA 控制串口，使用字符串 `Abc` 模式发送命令。

VOFA 按钮建议发送内容：

```text
MODE\r\n
REC\r\n
SAMPLE\r\n
STOP\r\n
SETREC 30 500\r\n
LABEL 0\r\n
LABEL 25\r\n
LABEL 50\r\n
LABEL 75\r\n
LABEL 100\r\n
LABEL 255\r\n
STATUS\r\n
ERRCLR\r\n
HELP\r\n
```

当前命令含义：

| 命令 | 作用 |
|---|---|
| `MODE` | 在推理模式和采样模式之间反转 |
| `REC` | 连续采样开关，未开启则开始，已开启则停止 |
| `SAMPLE` | 单次采样一次 |
| `STOP` | 停止连续采样 |
| `SETREC n ms` | 设置连续采样次数和采样间隔 |
| `LABEL x` | 设置当前标签，`0~100` 或 `255` |
| `STATUS` | 输出当前模式、采样状态、连续采样配置、标签和错误状态 |
| `ERRCLR` | 清除错误标志和错误灯 |
| `HELP` | 输出命令帮助 |

当前默认连续采样参数：

```c
#define VOFA_DEFAULT_REC_COUNT  30U
#define VOFA_DEFAULT_REC_MS     500U
#define VOFA_LABEL_NONE         255U
```

### 2.4 LED 状态反馈

当前 LED 约定如下：

| LED | 含义 | 状态 |
|---|---|---|
| LED1 | 当前处于采样模式 | 亮 = SAMPLE，灭 = INFER |
| LED2 | 当前有采样请求正在等待写入完成 | 亮 = 正在采样/写入 |
| LED3 | 错误状态 | 亮 = 最近存在错误 |

LED 采用低电平点亮：

```c
#define VOFA_LED_ON   GPIO_PIN_RESET
#define VOFA_LED_OFF  GPIO_PIN_SET
```

## 3. 遇到的问题与解决过程

### 3.1 串口没有数据输出

问题表现：

- 一开始 USART1 没有调试输出。
- 使用官方/开发板例程测试串口通信正常，说明硬件本身没有问题。
- 后续 Debug 发现程序会卡在初始化流程中，导致串口打印没有机会执行。

原因分析：

- 程序初始化链路中包含 SD / FatFs 等外设。
- 当 SD 卡未插入或初始化异常时，可能进入错误路径。
- 这会导致后续 VL53 和串口调试逻辑没有继续运行。

解决方式：

- 暂时绕开会卡死的 SD 初始化问题。
- 后续恢复 SD 采样时，避免未插卡直接导致整体程序不可观察。
- 加入 LED 和串口状态输出，方便判断程序是否跑起来。

结果：

- USART1 能输出 VL53 调试信息。
- 可以通过串口看到传感器帧数据和 CSV 写入状态。

### 3.2 VL53 距离值显示异常，近似放大或比例错误

问题表现：

- 实际距离约 `20 cm`，显示却接近 `1000 mm`。
- 实际 `30 cm` 左右，显示约 `1500 mm`。
- 表现为数值明显按比例异常。

原因分析：

- VL53 ULD API 的输出格式配置与当前读取方式不匹配。
- 原始格式和普通 `distance_mm` 解释方式混用，导致距离值被错误解释。

解决方式：

- 关闭 `VL53LMZ_USE_RAW_FORMAT`。
- 让 `results->distance_mm[]` 直接按普通 mm 单位读取。

结果：

- 距离显示恢复准确。
- 后续 CSV 中的 `d0...d63` 可以作为真实距离输入特征使用。

### 3.3 CNH 如何理解和使用不清楚

问题表现：

- 对 `bin`、`直方图`、`回波`、`CNH` 的物理意义不清楚。
- 一开始容易把 CNH 当成普通距离值。

解释结果：

- VL53 发射光脉冲，物体反射回来形成回波。
- 回波到达时间对应距离。
- CNH 是把不同距离段内的回波强度整理成直方图。
- 每个 bin 表示一个距离段中的回波强度。
- 对于 8x8，每个 zone 都有一组 CNH bin。

当前用途：

- 距离矩阵 `distance[64]` 更适合定位手的位置和移动趋势。
- CNH `cnh[64][8]` 更适合表达手部形态、体积和反射分布，用于静态张握程度回归。

### 3.4 采样按钮不适合长期使用

问题表现：

- 使用实体按键触发采样太费手。
- 长期大量采样可能损坏按键。
- 按键操作也容易引入手部动作干扰。

解决方式：

- 改为通过 VOFA 串口命令控制采样。
- 单次采样、连续采样、模式切换、标签设置都由 VOFA 按钮发送字符串命令完成。

结果：

- 不再依赖实体按键。
- 可以用 VOFA 建多个按钮快速采集不同标签的数据。
- 连续采样可以指定次数和间隔，减少人工操作。

### 3.5 VOFA 只能发送字符串或十六进制

问题表现：

- VOFA 命令控件只能选择 `Abc` 字符串或 `Hex` 十六进制。

解决方式：

- 选择 `Abc` 字符串模式。
- 每条命令以 `\r\n` 结束。
- MCU 端以 `\r` 或 `\n` 作为命令结束符。

结果：

- 命令形式简单清晰。
- 不需要使用复杂二进制协议。
- 适合当前采样阶段。

### 3.6 SD CSV 保存可靠性问题

问题表现：

- 需要确认每次采样是否真的写入 SD。
- 需要避免文件没有 header 或列数不一致。
- 需要避免长时间打开文件导致断电风险。

解决方式：

- `CsvLogger_AppendLine()` 内部每次打开文件。
- 文件为空时写 header。
- 写数据行后 `f_sync()`。
- 最后 `f_close()`。
- 写入失败返回错误码并通过串口输出。

结果：

- CSV 数据可以持续写入。
- 每行列数固定。
- 断电风险比长期保持文件打开更低。

## 4. 当前已经完成的内容

### 4.1 VL53 基础测距

已完成：

- VL53 初始化。
- 8x8 分辨率输出。
- 距离矩阵读取。
- 距离单位修正为真实 mm。
- 中心 zone 串口调试输出。

当前输出示例语义：

```text
frame_count    当前读取帧计数
timestamp_ms   HAL tick 时间戳
z27 d=xxx      中心 zone 的距离 mm
st=xxx         target status
cnh_valid      CNH 是否成功提取
```

### 4.2 CNH 输出

已完成：

- CNH 配置。
- 创建 8x8 aggregate map。
- 通过自定义 output config 追加 CNH block。
- 使用 `vl53lmz_send_output_config_and_start()` 启动带 CNH 的 ranging。
- 使用 `vl53lmz_dci_read_data()` 提取 CNH block。
- 每个 zone 提取 8 个 bin。

当前 CNH 数据规模：

```text
64 zones * 8 bins = 512 个 CNH 特征
```

### 4.3 CSV 写入

已完成：

- 写入 `0:/gesture.csv`。
- 自动写 header。
- 写入 64 个距离值。
- 写入 512 个 CNH 值。
- 每次采样单独打开、同步、关闭文件。
- 写入结果通过 `VL53_App_ConsumeSampleResult()` 给 VOFA 层消费。

### 4.4 VOFA 控制模块

已完成：

- 新增独立目录：`Core/Vofa_debug`。
- 新增 `vofa.c` / `vofa.h`。
- 使用 USART1 DMA 环形缓冲接收字符串。
- 支持 `MODE`、`REC`、`SAMPLE`、`STOP`、`SETREC`、`LABEL`、`STATUS`、`ERRCLR`、`HELP`。
- `main.c` 中只调用：

```c
Vofa_Init();
Vofa_Task();
```

### 4.5 LED 状态

已完成：

- LED1 显示采样模式。
- LED2 显示采样等待/写入中。
- LED3 显示错误状态。

## 5. 当前解决方案的数据流

当前运行主流程：

```text
main()
  HAL_Init()
  SystemClock_Config()
  MX_GPIO_Init()
  MX_DMA_Init()
  MX_USART1_UART_Init()
  MX_I2C1_Init()
  MX_SDMMC1_SD_Init()
  MX_FATFS_Init()
  ...
  App_LedInit()
  VL53_App_Init()
  VL53_App_SetMode(INFER)
  Vofa_Init()

while(1)
  VL53_App_Task()
    check_data_ready
    get_ranging_data
    extract CNH block
    copy distance frame
    if sample pending and delay >= 500ms:
      build csv line
      append csv line to SD
      set sample result pending

  Vofa_Task()
    receive UART command line
    parse command
    update mode / label / record state
    consume sample result
    schedule next sample if REC active
```

当前采样流程：

```text
VOFA: LABEL 50\r\n
  -> MCU 保存当前 label_score = 50

VOFA: REC\r\n
  -> 开始连续采样
  -> 使用默认或 SETREC 设置的次数/间隔
  -> 每次触发 VL53_App_RequestSample()
  -> VL53 内部延时 500ms 后写 CSV
  -> 写完后 VOFA 层收到结果
  -> 成功则等待下一个 interval
  -> 次数耗尽则 OK REC DONE
```

当前单次采样流程：

```text
VOFA: SAMPLE\r\n
  -> 停止连续采样状态
  -> 进入 SAMPLE 模式
  -> 请求单次采样
  -> LED2 亮
  -> 写入完成后 LED2 灭
  -> 成功 LED3 灭，失败 LED3 亮
```

## 6. 当前仍存在的问题

### 6.1 `LABEL` 尚未写入 CSV

这是当前最重要的未完成项。

现在 `vofa.c` 内部已经保存了：

```c
g_state.label_score
```

但 `vl53_app.c` 写 CSV 时并不知道这个 label，所以当前 CSV 中还没有 `label_score` 字段。

当前 CSV：

```csv
timestamp_ms,frame_count,mode,valid,d0...d63,cnh...
```

目标 CSV 应改为：

```csv
timestamp_ms,label_score,frame_count,mode,valid,d0...d63,cnh...
```

或者：

```csv
timestamp_ms,frame_count,label_score,mode,valid,d0...d63,cnh...
```

建议下一步采用第一种，因为训练脚本更容易读：

```csv
timestamp_ms,label_score,frame_count,mode,valid,...
```

需要新增接口，让 VOFA 设置的 label 能被 VL53 CSV 写入使用。

建议最小修改：

```c
void VL53_App_SetLabelScore(uint8_t label_score);
uint8_t VL53_App_GetLabelScore(void);
```

然后 `vofa.c` 中执行 `LABEL x` 时同时调用：

```c
VL53_App_SetLabelScore((uint8_t)label);
```

### 6.2 当前没有离线训练脚本

还没有建立 PC 端训练流程。

后续需要：

1. 读取 `gesture.csv`。
2. 检查列数。
3. 分离 label、distance、CNH。
4. 做归一化。
5. 划分训练集/验证集。
6. 训练回归模型。
7. 导出 ONNX / TFLite / CubeAI 支持格式。
8. 使用 STM32CubeAI 做量化和代码生成。

### 6.3 当前未实现推理模式

`MODE INFER` 目前只是关闭采样写 SD，尚未真正运行模型推理。

后续推理模式应完成：

- 读取最新 VL53 frame。
- 组装模型输入。
- 调用 CubeAI 网络推理。
- 得到 `openness_score = 0~100`。
- 做滤波。
- 输出给控制逻辑。
- 最终通过 CANFD 发给电机板。

### 6.4 当前没有 CANFD 控制摘要发送

当前 CANFD 最终目标尚未实现。

目标是 H743 向电机板发送控制摘要，不发送原始 CNH。

建议 payload 包含：

```text
magic
version
seq
valid
openness_score
center_x
center_y
center_z_mm
motion_x
motion_y
motion_z
state
flags
crc
```

### 6.5 当前采样间隔语义需要进一步确认

当前 `REC` 逻辑是：

1. 发送 `REC` 后立刻触发第一帧采样。
2. VL53 内部等待 500ms 后写入。
3. 写入成功后等待 `record_interval_ms`。
4. 再触发下一帧。

所以实际相邻 CSV 行之间的时间大约是：

```text
500ms 稳定等待 + record_interval_ms + 文件写入时间
```

如果希望 `SETREC 30 500` 表示“CSV 行之间约 500ms”，则需要改调度语义。

当前更准确的理解是：

```text
每次写入前先稳定 500ms，写完后再等 interval_ms 再发下一次采样请求。
```

### 6.6 当前 SD 写入是可靠优先，不是速度优先

每次写入都 open/sync/close，稳定但较慢。

如果后续需要高频采样，可能要改为：

- 采样开始时打开文件。
- 连续采样期间保持文件打开。
- 每 N 行或每 1 秒 sync 一次。
- 采样结束后 close。

但当前阶段不建议马上改，因为可靠性和简单性更重要。

### 6.7 当前 VOFA 打印是阻塞式

`Vofa_Printf()` 使用：

```c
HAL_UART_Transmit(..., HAL_MAX_DELAY)
```

当前采样频率较低，问题不大。

如果后续进入实时控制和 CANFD 高频运行，需要改为：

- 降低打印频率。
- 或使用 UART DMA TX 队列。
- 或最终关闭调试打印。

### 6.8 当前没有完整错误恢复策略

现在错误主要表现为 LED3 亮和串口返回 `ERR xxx`。

还没有完整区分：

- SD 未插卡。
- SD mount 失败。
- 文件打开失败。
- CNH 提取失败。
- VL53 通信失败。
- UART RX 异常。

后续可以把错误码进一步标准化。

## 7. 后续优化建议

### 7.1 优先补齐 label 写入 CSV

这是下一步最高优先级。

原因：

- 没有 label 的 CSV 不能直接用于监督训练。
- 当前 VOFA 已经能设置 label，只差接到 CSV。

建议目标 CSV：

```csv
timestamp_ms,label_score,frame_count,mode,valid,d0...d63,cnh_z0_b0...cnh_z63_b7
```

其中：

- `label_score = 0~100` 表示有效手势张握程度。
- `label_score = 255` 表示无手数据。
- `valid` 表示当前帧目标是否有效。

### 7.2 增加 CSV 文件元信息

可以在 CSV 文件开头或单独 `meta.txt` 记录：

```text
sensor=VL53L8CH
resolution=8x8
cnh_start_bin=6
cnh_num_bins=8
cnh_sub_sample=1
sample_delay_ms=500
firmware_date=...
```

这样以后训练时不会忘记数据采集参数。

但第一版可以先不做，避免复杂化。

### 7.3 增加采样质量字段

后续可以在 CSV 中增加：

- 有效 zone 数量。
- 中心距离。
- 平均距离。
- 最近错误码。

这些字段可以帮助离线清洗数据。

但第一版训练不一定需要。

### 7.4 明确训练标签策略

建议第一批数据先采：

```text
LABEL 255  无手
LABEL 0    尽量握拳
LABEL 25   偏握拳
LABEL 50   中间状态
LABEL 75   偏张开
LABEL 100  尽量张开
```

每个标签多采不同距离、不同手型、不同位置：

- 250mm。
- 300mm。
- 350mm。
- 400mm。
- 450mm。
- 中心位置。
- 偏左、偏右、偏上、偏下。

这样比只在一个固定位置采更有泛化能力。

### 7.5 训练模型建议

第一版建议仍然采用小模型回归：

```text
input = distance[64] + cnh[64][8] = 576
output = openness_score 0~100
```

模型可以从小 MLP 开始：

```text
576 -> 16 -> 1
```

或者：

```text
576 -> 32 -> 8 -> 1
```

如果 CubeAI 量化后速度和 RAM 都够，再考虑加大模型。

### 7.6 推理输出滤波

即使模型输出连续值，也建议做滤波：

```text
score_filtered = score_filtered * 0.8 + score_new * 0.2
```

或者用整数滤波：

```c
filtered = (filtered * 4 + score_new) / 5;
```

这样可以减少手轻微抖动导致的控制抖动。

### 7.7 分离静态识别和动态检测

当前思路是合理的：

- 静态时使用 CNH + distance 做张握程度推理。
- 动态移动时主要使用 8x8 distance 做位置和速度检测。
- 不要求在快速移动过程中实时更新手势张握程度。

这样可以降低模型计算压力，也更符合应用需求。

## 8. 达到最终目标还需要完成的任务

### 阶段 1：补齐采集数据闭环

必须完成：

1. 将 `label_score` 写入 CSV。
2. 确认 VOFA `LABEL` 设置后，下一次 `SAMPLE/REC` 写入正确标签。
3. 采一小批数据并检查 CSV 列数、header、标签是否正确。
4. 确认无手 `255` 数据能被保存。

验收标准：

```text
gesture.csv 中每一行都有 label_score 字段。
不同 VOFA LABEL 按钮采到的数据标签正确。
CSV 行列数固定且可被 Python 读取。
```

### 阶段 2：批量采集训练数据

建议流程：

```text
MODE
SETREC 30 500
LABEL 255
REC
LABEL 0
REC
LABEL 25
REC
LABEL 50
REC
LABEL 75
REC
LABEL 100
REC
```

每个标签建议多轮采集，改变手的位置、距离和角度。

验收标准：

```text
每个标签至少有几百行可用数据。
CSV 中 valid、distance、CNH 数据合理。
无明显空行、断列、重复 header。
```

### 阶段 3：PC 端训练

需要实现：

1. CSV 读取脚本。
2. 数据清洗。
3. 特征归一化。
4. 回归模型训练。
5. 验证误差评估。
6. 导出 CubeAI 可转换模型。

验收标准：

```text
验证集上 0~100 输出趋势正确。
握拳接近 0，张开接近 100，中间状态输出合理。
无手数据能被识别或被 valid 逻辑过滤。
```

### 阶段 4：CubeAI 部署

需要完成：

1. 使用 STM32CubeAI 导入模型。
2. 配置量化。
3. 生成推理代码。
4. 在 H743 工程中接入 AI 初始化和推理。
5. 对比 PC 输出和 MCU 输出。

验收标准：

```text
同一组输入在 PC 和 MCU 上输出接近。
MCU 推理时间满足控制需求。
RAM/Flash 占用可接受。
```

### 阶段 5：控制逻辑与 CANFD 通讯

需要完成：

1. 从 8x8 distance 计算手部中心位置。
2. 计算移动方向和速度。
3. 融合 `openness_score + position + motion`。
4. 定义 CANFD payload。
5. H743 发送控制摘要。
6. 电机板接收并解析。
7. 异常状态下进入安全状态。

验收标准：

```text
H743 能稳定发送 0~100 张握程度和位置/运动摘要。
电机板能解析 CANFD 数据并做安全控制。
丢帧、无手、错误状态下不会输出危险动作。
```

## 9. 当前风险点

### 9.1 CubeMX 重新生成覆盖问题

当前 `vofa.c/h` 是用户新增模块，不属于 CubeMX 自动生成区。

风险较低。

但 `main.c` 中调用 `Vofa_Init()` 和 `Vofa_Task()` 必须放在 USER CODE 区域内，否则 CubeMX 重新生成可能丢失。

重新生成后必须检查：

```text
main.c 是否仍 include vofa.h
main.c USER CODE BEGIN 2 是否仍调用 Vofa_Init()
main.c USER CODE BEGIN 3 是否仍调用 Vofa_Task()
Keil 工程是否仍包含 vofa.c
IncludePath 是否包含 ../Core/Vofa_debug
```

### 9.2 Keil 工程文件改动较大

之前加入 `vofa.c` 到 Keil 工程时，`.uvprojx` 可能出现较大的格式变化。

后续提交前需要特别检查：

```text
H743VIT6/MDK-ARM/H743VIT6.uvprojx
```

确认只保留必要的新增 include path 和 `vofa.c` 文件加入，不要混入无关工程配置变化。

### 9.3 当前仓库中有大量历史未跟踪/修改文件

`git status` 显示当前工作区存在大量旧改动和未跟踪文件。

后续提交时必须小心，只提交本功能相关文件，避免把旧快照、node_modules、Keil 个人文件等一起提交。

建议提交范围：

```text
H743VIT6/Core/Vofa_debug/vofa.c
H743VIT6/Core/Vofa_debug/vofa.h
H743VIT6/Core/Src/main.c
H743VIT6/MDK-ARM/H743VIT6.uvprojx
H743VIT6/Core/vl53_app/vl53_app.c
H743VIT6/Core/vl53_app/vl53_app.h
H743VIT6/Core/Src/csv_logger.c
H743VIT6/Core/Inc/csv_logger.h
```

具体以每一步实际修改为准。

## 10. 下一步建议

下一步建议按最小修改继续：

1. 给 `VL53_App` 增加 `label_score` 状态和 setter/getter。
2. `vofa.c` 的 `LABEL x` 命令调用 `VL53_App_SetLabelScore(x)`。
3. 修改 CSV header 和 CSV 行，把 `label_score` 写入第二列。
4. 更新 `VL53_APP_CSV_COLUMNS`，从 `580` 变成 `581`。
5. 上板测试：

```text
LABEL 0
SAMPLE
LABEL 100
SAMPLE
STATUS
```

6. 拿 SD 卡查看 `gesture.csv`：

```csv
timestamp_ms,label_score,frame_count,mode,valid,...
```

确认两行标签分别是 `0` 和 `100`。

完成这个之后，才真正具备训练数据采集闭环。

## 11. 当前结论

当前项目已经从“传感器能否跑起来”推进到“可以开始组织训练数据采集”的阶段。

已经完成的关键基础：

- VL53 8x8 距离矩阵稳定输出。
- CNH 输出链路打通。
- 距离单位问题已修正。
- SD CSV 写入链路可用。
- VOFA 字符串命令控制框架已建立。
- 单次采样和连续采样状态机已具备雏形。
- LED 能反馈采样模式、采样等待和错误状态。

当前最关键的缺口：

```text
LABEL 已能通过 VOFA 设置，但还没有写入 CSV。
```

因此下一步不应直接开始大量采数据，而应先把标签写入 CSV。否则采出来的数据无法直接用于监督训练。

## 12. 2026-07-05 最新问题复盘与当前状态

本节记录从早期采集链路打通之后，到当前 H7 主控侧已经实际完成和修正的问题。这里的内容以当前代码状态为准。

### 12.1 当前 H7 的真实定位

当前 H7 已经不只是“采集板”，而是承担手势主控的完整上层任务：

```text
VL53L8CH 8x8 + CNH
  -> CSV 数据采集
  -> PC 端 CNN/MLP 训练
  -> CubeAI 部署推理
  -> openness_score 0~100
  -> 手部中心位置 / 距离 / 弯曲程度 / 刚度
  -> CANFD 下发给 G4 三电机板
  -> W25Q64 保存 HOME / ACTUAL 位置记录
```

当前 `main()` 主流程已经包含：

```c
Can_App_Init();
MotorControl_Init();
VL53_App_Init();
VL53_App_SetMode(VL53_APP_MODE_INFER);
Vofa_Init();

while (1)
{
  MX_X_CUBE_AI_Process();
  VL53_App_Task();
  Vofa_Task();
  MotorControl_Task();
}
```

说明：

- `VL53_App_Task()` 负责传感器帧、CNH、CSV、AI 前处理和推理。
- `Vofa_Task()` 负责串口命令、采样状态机、CAN/W25Q64 调试命令。
- `MotorControl_Task()` 负责把 AI 输出映射为触手控制目标，并通过 CANFD 发给 G4。

### 12.2 CSV 字段已经补齐，早期“label 未写入 CSV”已解决

早期文档中记录的主要缺口是 `LABEL` 尚未写入 CSV。当前已经解决。

当前 CSV 表头由 `VL53_App_BuildCsvHeader()` 生成，字段为：

```text
timestamp_ms,label_score,frame_count,mode,valid,
d0...d63,
target_status_z0...target_status_z63,
nb_target_z0...nb_target_z63,
cnh_z0_b0...cnh_z63_b7
```

当前列数：

```text
5 + 64 + 64 + 64 + 64*8 = 709 列
```

解决内容：

- `vofa.c` 的 `LABEL x` 命令会调用 `VL53_App_SetLabelScore()`。
- `VL53_App_WriteCsvFrame()` 会把 `g_vl53_label_score` 写入第二列。
- CSV 写入前会用 `VL53_App_CountCsvColumns()` 检查列数。
- 表头和数据行都按 `VL53_APP_CSV_COLUMNS` 校验，避免训练脚本读到错列数据。

当前结论：

```text
CSV 已经满足训练数据格式要求。
label_score、target_status、nb_target_detected、distance、CNH 均已进入数据集。
```

### 12.3 CSV 坏行、错行和文件损坏问题

问题表现：

- 早期采集得到的 CSV 中出现过错行、坏行。
- 有时电脑读取 SD 卡时提示根目录或文件损坏。
- VOFA 显示写入成功，但电脑端看不到完整文件或无法正常打开。
- 快速格式化 SD 卡后可恢复，说明问题更偏向文件系统写入/缓存/同步时序，而不是卡完全坏掉。

原因分析：

1. 采样过程中如果频繁打开/关闭文件，文件系统元数据会反复更新。
2. 如果写入期间掉电或拔卡，目录项和 FAT 可能不一致。
3. H743 开启 DCache 后，SDMMC DMA 读写如果没有做 cache 维护，容易出现 CPU 缓存与 DMA 实际内存不一致。
4. FatFs 的部分缓冲区可能不是 32 字节对齐，DMA 和 DCache 维护时需要 scratch buffer。

解决方式：

- `sd_diskio.c` 启用：

```c
#define ENABLE_SD_DMA_CACHE_MAINTENANCE  1
#define ENABLE_SCRATCH_BUFFER
```

- 对 SD DMA 读使用 `SCB_InvalidateDCache_by_Addr()`。
- 对 SD DMA 写使用 `SCB_CleanDCache_by_Addr()`。
- scratch buffer 改为 32 字节对齐：

```c
ALIGN_32BYTES(static uint8_t scratch[BLOCKSIZE]);
```

- 未对齐写入路径中，在 `memcpy()` 到 scratch 后、启动 SD DMA 写卡前，额外执行 DCache clean。
- `CsvLogger_AppendLine()` 保持文件打开状态时仍然每行 `f_sync()`，写失败会关闭文件。
- `VL53_App_SetMode(INFER)` 和采样停止路径都会调用 `CsvLogger_Close()`，降低文件长时间占用风险。

结果：

- SD DMA 与 DCache 的一致性问题已做维护。
- 未插卡不再应该让主程序直接卡死在 `Error_Handler()`。
- CSV 写入仍需注意：采样结束后应先发送 `STOP` 或等待 `DONE`，再断电或拔卡。

当前建议：

```text
采样结束后：
1. 等待 NORMAL DONE / BAL DONE / OK STOP。
2. 确认 LED2 灭。
3. 再断电或拔 SD 卡。
```

### 12.4 未插 SD 卡导致程序卡死问题

问题表现：

- 不插 SD 卡时，程序可能在 SD 初始化阶段进入错误路径。
- 这会导致串口、VL53、VOFA 都没有机会继续运行。

解决方式：

`MX_SDMMC1_SD_Init()` 中，`HAL_SD_Init(&hsd1)` 失败后不再 `Error_Handler()`，而是直接 `return`：

```c
if (HAL_SD_Init(&hsd1) != HAL_OK)
{
  return;
}
```

结果：

- 未插 SD 卡时主程序仍能继续跑。
- 真正需要写 CSV 时，由 FatFs / CsvLogger 返回错误码。
- 这让 H7 在没有 SD 卡时仍然可以作为推理和 CAN 主控使用。

### 12.5 VOFA 采样控制已经扩展为普通采样和均衡采样

当前 VOFA 命令已经明显多于早期版本。

采样相关命令：

| 命令 | 作用 |
|---|---|
| `MODE` | 采样模式 / 推理模式切换 |
| `SAMPLE` | 单次采样 |
| `REC` | 开始或停止连续采样 |
| `STOP` | 强制停止采样并切回推理模式 |
| `SETREC n ms` | 设置普通连续采样次数和间隔，同时切换为普通采样模式 |
| `BALCFG start end step target ms` | 设置距离均衡采样参数，同时切换为均衡采样模式 |
| `LABEL x` | 设置标签，`0~100` 或 `255` |
| `STATUS` | 查看当前模式、采样状态、标签、错误和均衡采样统计 |
| `ERRCLR` | 清除错误灯 |
| `HELP` | 输出命令说明 |

均衡采样的目的：

- 解决数据集中某些距离段样本过多、某些距离段样本过少的问题。
- 采样前先用当前 VL53 帧计算手部中心距离 `center_z_mm`。
- 按距离分桶，只保存目标距离档还没满的样本。
- 不符合距离范围或该桶已满时跳过，不写 CSV。

均衡采样输出格式：

```text
BALCNT label=50 total=xx/yy target=20
DIST   180  200  220 ...
COUNT    5    8   20 ...
```

结果：

- 可以直接观察每个距离档已经采了多少条。
- 适合补充边缘距离数据，例如 `180~220mm`、`380~420mm`。

### 12.6 采样超时和自动重试机制

问题表现：

- 连续采样过程中，LED2 曾经长亮。
- 串口看起来卡住。
- 可能是某次 SD 写入、VL53 状态或 FatFs 操作没有在预期时间返回。

解决方式：

VOFA 层加入采样超时控制：

```c
#define VOFA_SAMPLE_TIMEOUT_MS  3000U
#define VOFA_SAMPLE_MAX_RETRY   3U
```

行为：

- 每次 `Vofa_StartSample()` 后设置 `sample_deadline_ms`。
- 如果 `VL53_App_ConsumeSampleResult()` 超时未返回，VOFA 会结束本次等待。
- 连续采样中，如果未超过最大重试次数，会打印：

```text
WARN SAMPLE_TIMEOUT_RETRY x/3
```

- 超过重试次数后，强制停止采样，切回推理模式，打印：

```text
ERR SAMPLE_TIMEOUT
```

结果：

- LED2 长亮和采样状态卡死问题得到缓解。
- 发生异常时系统能回到可继续控制的状态，而不是一直等待。

### 12.7 VL53 有效距离、前景和 ROI 问题

当前 AI 前处理有效距离范围：

```c
#define VL53_APP_AI_VALID_MIN_MM        160
#define VL53_APP_AI_VALID_MAX_MM        450
#define VL53_APP_AI_FOREGROUND_MARGIN   120
```

有效 zone 判断：

```text
distance 在 160~450mm
target_status == 5 或 9
nb_target_detected > 0
```

前景判断：

```text
hand zone = 有效 zone 且 distance <= d_min + 120mm
```

遇到的问题：

- 只用距离判断前景时，手臂可能也会被算入前景。
- 远近变化会影响张握程度判断，容易让模型“偷学距离”。
- ROI 计算早期经常显示 `0~7` 整个区域，说明根据当前 FOV 和手掌尺寸估算出的 ROI 很容易覆盖全图。
- VL53L8CH 的视场角理解曾出现偏差，后续改为用更保守的等效半角计算。

当前处理方式：

- ROI 调试仍保留，用于观察手部区域估计，但当前 CNN 输入主要仍基于全图固定 `20x8x8` 特征。
- 不把动态 ROI 裁剪成可变输入，避免模型输入尺寸不稳定。
- 使用全图 mask 和全局复制特征，让模型自己学习“哪里是手、哪里可能是手臂干扰”。

当前结论：

```text
ROI 当前主要用于调试和手部位置观察，不是最终训练输入的唯一依据。
当前 CNN 输入保持固定 20x8x8，便于 CubeAI 部署。
```

### 12.8 CNN 模型和 CubeAI 部署问题

早期文档中的训练方案是 MLP：

```text
distance[64] + CNH[64][8] = 576
```

后续实际测试发现：

- MLP 在 300mm 附近表现较好。
- 离开主要训练距离后误差明显变大。
- 手臂干扰和距离变化会导致模型误判。

因此引入 CNN 版本：

```text
输入：20 x 8 x 8
输出：openness_score 0~100
```

20 个通道包含：

- 相对距离。
- 绝对距离归一化。
- 有效点 mask。
- 前景 mask。
- `target_status` 有效状态。
- `nb_target_detected`。
- 8 个 CNH bin。
- 复制到全图的手部中心 `x/y/z`。
- 前景 zone 数量。
- 前景外接矩形宽度和高度。

当前部署方式：

- PC 端训练脚本位于 `H743VIT6/Training`。
- CNN 模型导出 ONNX。
- 使用 STM32CubeAI 导入、Analyze、Validation Desktop 后生成代码。
- MCU 端通过 `GestureAI_Run()` 推理。
- `VL53_App_UpdateAiEstimate()` 得到 `openness_score`。

当前串口显示：

```text
当前手掌张握程度：xx
```

已经验证过：

```text
当前模型在主要采样距离内效果可以，实时显示比较直观。
```

仍需注意：

- 当前模型精度强依赖训练数据覆盖范围。
- `340~420mm` 或边缘距离误差曾变大，需要继续补充数据。
- 如果改 CSV 特征或前处理参数，必须重新训练并重新导出 CubeAI 模型。

### 12.9 X-CUBE-AI / DCache 相关问题

问题背景：

- 使用 CubeAI 后，DCache 不能轻易关闭，或者关闭选项不可用。
- H7 开启 DCache 后，SDMMC DMA、串口 DMA、AI 输入缓冲等都要注意缓存一致性。

当前处理：

- 主程序开启 ICache 和 DCache。
- SDMMC DMA 已在 `sd_diskio.c` 做 cache maintenance。
- VOFA UART RX buffer 使用 32 字节对齐。

原则：

```text
DMA 写内存：CPU 读之前 invalidate。
CPU 写内存给 DMA 读：DMA 启动前 clean。
```

当前仍需注意：

- 后续如果新增 I2C DMA、UART TX DMA 队列、SPI/QSPI DMA，都要检查对应 buffer 的对齐和 cache 维护。
- AI 输入当前由 CPU 写入并由 CPU 调用推理，通常不涉及外设 DMA，但仍要避免把 DMA buffer 直接作为 AI 输入使用。

### 12.10 W25Q64 保存 HOME / ACTUAL 位置记录

问题背景：

- W25Q64 的主要目的不是大量存训练数据，而是掉电后恢复触手位置参考。
- 需要保存 G4 反馈的实际多圈位置，以及用户设置的 HOME 初始点。

当前命令：

| 命令 | 作用 |
|---|---|
| `W25ID` | 读取 JEDEC ID |
| `W25TEST` | 擦写读回测试 |
| `W25SAVE` | 保存当前 G4 actual 位置 |
| `W25LOAD` | 读取最新 HOME 和 ACTUAL |
| `CANZERO` | 将当前 G4 actual 作为 H7 HOME，并保存 HOME / ACTUAL |
| `MSETZERO q0 q1 q2` | 手动设置 H7 HOME 并保存 |

遇到的问题：

- 早期记录扫描和结构体大小绑定较紧，存在写入后读取异常风险。
- 需要确保写入成功不是只看 HAL 返回，而要能断电后恢复。

解决方式：

- 使用固定 64 字节日志槽：

```c
#define W25Q64_APP_LOG_SLOT_SIZE    64UL
```

- 记录带 `magic/version/size/type/seq/position/tick/crc32`。
- 保存后立即读回，检查：

```text
magic/version/type/crc/memcmp
```

结果：

已经出现过成功输出：

```text
OK W25LOAD home_seq=33 home=136,-172,844 actual_seq=114 actual=136,-172,844
```

说明 W25Q64 保存、扫描、读回校验链路已经可用。

### 12.11 CANFD 与 G4 通讯问题

当前 H7 和 G4 使用 CANFD 进行控制。

H7 发送：

```text
标准 ID 0x120
CAN FD + BRS
32 bytes payload
q 单位 = rad * 100
```

G4 状态帧：

```text
标准 ID 0x180
32 bytes payload
actual_q[0..2] 位于 byte20~31
```

H7 当前命令：

| 命令 | 作用 |
|---|---|
| `CANSTAT` | 查看 G4 在线、错误、mask、pwm、actual_q |
| `CANSTOP` | 停止 G4 三路输出 |
| `CANZERO` | 当前 G4 actual 作为 H7 HOME 并保存 |
| `CANHOME` | 发送 HOME 绝对目标，带 RESET |
| `CANPOS/CANREL dq0 dq1 dq2` | 发送相对位置命令 |
| `CANABS q0 q1 q2` | 发送 `HOME + input` 的绝对目标 |

重要语义：

```text
CANZERO：
  H7 保存 HOME，不直接让 G4 修改编码器零点。

CANHOME：
  H7 向 G4 发送 HOME 绝对目标，让 G4 位置环回到初始点。

CANPOS/CANREL：
  相对 G4 最新 actual_q 加增量。

CANABS：
  相对 H7 HOME 的绝对目标。
```

曾遇到的问题：

- `CANPOS 1000 1000 1000` 含义容易误解。实际单位是 `0.01rad`，所以 `1000 = 10rad`。
- H7 显示 target 早期没有使用 `actual + input`，导致相对命令显示不直观。
- G4 端如果三电机不是同步动，需要看 `CANSTAT` 中的 `mask/pwm/flags/actual_q`。
- 若只有某个电机动，问题更可能在 G4 端 PWM/ADC/闭环执行链，不是 H7 只发了一路。

当前 H7 侧已做：

- 相对命令要求 G4 状态新鲜，否则返回 `CAN_STALE`。
- `CANHOME` 和 `CANABS` 发送绝对目标时带 RESET。
- `CANSTAT` 可以显示：

```text
ready, tx, g4_valid, online, age, rx, g4rx, g4tx, err,
last_seq, cmd, flags, mask, pending, pwm, aq0,aq1,aq2
```

### 12.12 触手映射控制层

H7 已经加入 `motor_control_app`，用于把 AI 输出转换成三电机目标。

当前输入：

```text
ai->x, ai->y              手部平面位置，-100~100
ai->bend_0_100            弯曲程度，100 - openness_score
ai->stiffness_0_100       根据 center_z 得到的刚度
ai->center_z_mm           手部距离
```

当前输出：

```text
pull_q[3]    相对 HOME 的三根线拉动量
target_q[3]  发给 G4 的三电机绝对目标
```

方向关系已经按实际机构修正：

```text
电机2收缩 -> 空间角度 -135°
电机3收缩 -> 空间角度 -15°
电机1收缩 -> 空间角度 105°
```

工作区定义：

```text
-45° 到 135° 为前方工作区
135° 到 -45° 为后方工作区
```

当前控制策略：

- `x/y` 只表达方向。
- `bend_0_100` 表达弯曲程度。
- `stiffness_0_100` 表达共同预紧/刚度。
- 不周期重复发送同一个目标，目标变化时发送一次，由 G4 位置环保持。

仍需注意：

- H7 只负责生成合理目标，G4 端位置环必须先稳定。
- 当前 G4 端仍在排查三电机位置环和方向一致性问题，因此 H7 的映射层需要等 G4 基础闭环稳定后再做最终联调。

### 12.13 当前还没完全解决的问题

1. G4 三电机位置环还在联调中。

H7 CAN 发送和 G4 状态解析已通，但如果 G4 端只有某一路动、KEY2 本地测试乱转，问题更可能在 G4 的编码器方向、位置环反馈符号、ADC/TIM 触发链或按键测试路径，不属于 H7 单侧能完全解决的问题。

2. 模型在边缘距离仍可能误差变大。

当前 CNN 在主要采样距离内效果可以，但边缘距离和手臂干扰仍需要继续补数据和验证。建议继续使用均衡采样补 `180~220mm`、`380~420mm` 等距离段。

3. ROI 仍主要用于调试。

ROI 目前不能完全解决手臂干扰，也不应直接改成动态尺寸输入。后续如果要强化 ROI，应先在 PC 端脚本验证再同步 MCU 前处理。

4. SD 卡仍需按流程停止后再拔卡。

即使已经做 DCache 维护和 `f_sync()`，FAT 文件系统仍不适合在写入中直接断电。大量采集后建议等待 `DONE/STOP`。

5. CubeMX 重新生成后需要复查用户区。

尤其要检查：

```text
main.c 中 Can_App_Init / MotorControl_Init / VL53_App_Init / Vofa_Init
main.c while 中 VL53_App_Task / Vofa_Task / MotorControl_Task
sdmmc.c 未插卡 return 逻辑
sd_diskio.c DCache 维护和 scratch buffer
Keil 工程是否包含新增模块
```

### 12.14 当前最新结论

H7 侧已经完成：

- VL53L8CH 8x8 距离读取。
- CNH 8 bin 输出。
- CSV 采集字段补齐到 709 列。
- VOFA 普通采样和距离均衡采样。
- SDMMC DCache 维护和未插卡不阻塞。
- CNN 训练脚本和 CubeAI 推理接入。
- 串口显示 `当前手掌张握程度：xx`。
- W25Q64 HOME / ACTUAL 位置记录保存和读回校验。
- CANFD 与 G4 状态帧解析和位置命令发送。
- 初步触手映射控制层。

当前下一阶段重点：

```text
先把 G4 三电机位置环、方向、CAN 执行路径彻底稳定；
再回到 H7，使用当前 AI 输出和映射层做 H7->G4 实机联调。
```

---

## 13. 2026-07-06 至 2026-07-18 后续问题与解决记录

本章从第 12 章停止的位置继续记录。每项按“现象、原因、处理、当前结果”整理；尚未完成实机闭环验证的内容明确标为“待验证”，避免把临时缓解误写成彻底解决。

### 13.1 2026-07-06：CNN 推理、映射控制和位置保存链路合并

现象：

- CNN 已能在 H7 上输出手掌张握程度，但模型输出、手部平面位置、三电机目标和 G4 实际角度之间缺少统一数据流。
- HOME、断电前 ACTUAL 和 G4 上电后的多圈机械角度基准容易混淆，错误改写多圈角度曾导致电机高速乱转。
- 相对位置命令显示的 TARGET 一度只是输入增量，不是“当前位置 + 增量”，不便判断位置环是否正确。

原因判断：

- AI 输出属于手势空间，G4 位置环使用机械多圈角度，两者之间必须经过 H7 映射层和统一的正负方向约定。
- HOME 是回零目标，ACTUAL 是保存时的实际位置，不能互相替代；恢复坐标时也不能直接改动 FOC 使用的原始机械角度链路。

处理方法：

- H7 建立 `x/y + bend + stiffness -> 三路相对拉索量 -> G4 位置目标` 的映射流程。
- W25Q64 保存每个触手的 HOME、ACTUAL 和控制配置，并通过 RESTORE 有效标志约束启动。
- 相对位置调试输出改为显示“当前实际位置 + 输入增量”得到的目标。
- 对涉及多圈角度基准的修改坚持先停止电机，再进行坐标同步，避免运行中直接替换闭环反馈量。

当前结果：

- CNN、VOFA、映射控制、CAN 和 W25Q64 已形成完整基础链路。
- 正常上电恢复可以使用保存记录继续工作，但“运行中断连后 G4 可能被外力移动”的情况不能使用 H7 旧 ACTUAL 覆盖 G4，见 13.9。

### 13.2 2026-07-07 至 2026-07-09：迁移到 H743VIT6 新板

现象：

- 新板按键、LED 引脚及有效电平与旧板不同，外部 Flash 由 QSPI 改为 SPI4。
- CubeMX/X-CUBE-AI 重新生成后出现 `ai_platform.h` 路径丢失、旧 QSPI 引用残留、时钟初始化进入 Error_Handler、未插 SD 卡进入错误流程等问题。
- VL53 在 PB8/PB9 上总线保持低电平，扫描不到设备；相同传感器在另一块主控板上正常。

原因判断：

- 新旧板不能只复制业务文件，CubeMX 外设配置、Keil include path 和生成后需要补回的用户代码必须同时迁移。
- AI 生成代码、SDMMC/FatFs 和 DCache 维护代码中存在不在稳定 USER CODE 区内的内容，重新生成后容易被覆盖。
- PB8/PB9 在新板上的实际硬件状态不满足 I2C 空闲高电平条件。

处理方法：

- 以 `H743VIT6(new)` 为新主工程，重新生成 X-CUBE-AI 并补回 AI 调用、未插卡不进入 Error_Handler、SD DCache 对齐缓冲区等逻辑。
- W25Q64 驱动改走 SPI4，清理业务层对旧 QSPI 句柄的依赖。
- VL53 I2C 从 PB8/PB9 迁移到 PB10/PB11；先用 100 kHz 排查，通信成功后恢复 400 kHz，并保留上电延时和初始化重试。

当前结果：

- 新板可完成 VL53 采集、CNN 推理、W25Q64 访问、CAN 和串口调试。
- CubeMX 每次重新生成后仍需复查 AI include path、SD 未插卡处理和 DCache 缓冲区，不能只看“生成成功”。

### 13.3 2026-07-09 至 2026-07-11：三拉索方向、放线限制和堵转保护

现象：

- POS 单独控制正常，但映射控制时可能出现某一根绳过松、另一根持续拉紧，电机发热或需要轻推后才能继续转动。
- 对三路目标分别限幅会破坏原有比例关系，导致方向改变、卷曲不足或反方向只能运动一部分。
- 堵转后保持原目标会持续输出电流，电机温升明显；清除错误后有时仍不能恢复。

原因判断：

- H7 显示方向、CAN 命令方向和实际收放线方向曾存在多层符号转换，板间差异进一步放大了混乱。
- 三拉索是关联运动，不能只截断某一路；单路限幅后，三路差分关系被破坏。
- 仅以位置变化判断堵转容易误判静摩擦，仅看电流又会把正常大负载当成堵转。

处理方法：

- 统一 H7 的语义：正值表示收线，负值表示放线；每块 G4 的实际差异只通过触手方向表修正。
- 当任一路达到放线边界时，对三路差分量进行同比例缩放，保持运动方向和三路相对关系。
- 当前默认参数为：弯曲增益 `27000 q`、刚度增益 `2000 q`、最大放线量 `30000 q`，其中 `1 q = 0.01 rad`。
- 堵转判断组合使用“大电流 + 目标误差较大 + 一段时间内实际位置变化很小”；触发后目标改为当前位置并退出持续保持，STOP 同时清理堵转状态。

当前结果：

- 同比例缩放避免了“只限制一根绳”造成的方向畸变，反方向运动范围也比固定小放线量更完整。
- 堵转逻辑已降低误触发，但减速机静摩擦、绳索预紧不一致和单电机异常发热仍需逐板实测，不能仅靠提高电流阈值解决。

### 13.4 2026-07-10 至 2026-07-12：从双触手扩展到四触手

现象：

- 第二块 G4 接入后，原先只保存一套 HOME/ACTUAL 和只使用一个 CAN 节点号的结构无法区分触手。
- 切换触手后可能读到上一触手的数据，设置零点和回零也容易操作错对象。
- 后续四块 G4 如果复制四份代码，维护和烧录时很容易出现参数版本不一致。

原因判断：

- CAN 地址、闭环反馈方向和 FOC 微调属于板级差异；HOME、ACTUAL 和映射配置属于触手运行数据，两类配置不能混为一套全局变量。

处理方法：

- G4 使用统一 `board_profiles.h`，通过板号宏选择 CAN 节点号、三电机闭环反馈方向和 FOC 微调参数。
- H7 将 4 个触手映射为固定索引和 CAN ID，TSEL 只选择调试对象，工作模式决定实际活动掩码。
- W25Q64 改为按触手保存运行记录，HOME 和 ACTUAL 合并到同一快照，只更新发生变化的触手。
- 保存区采用版本、序号、有效标志和 CRC 校验；擦除过程改为任务化处理，减少一次阻塞整个控制循环的时间。

当前结果：

- 单触手可独立选择，双触手支持 1/2 或 3/4 分组，四触手具备统一分发基础。
- 四块 G4 仍需分别烧录对应板号配置，但业务代码保持一份，避免四份源代码长期分叉。

### 13.5 2026-07-12 至 2026-07-13：工作模式和协同关系整理

现象：

- 单触手、双触手和四触手命令混用时，STOP、HOME、POS 和映射目标的作用对象不清楚。
- 两个触手安装方向对称，直接复制相同 `x/y` 会出现实际方向相差 180°。
- 四触手中心对称控制中，触手 4 曾出现三根线都放松，而期望是电机 1、3 收线，电机 2 放线。

处理方法：

- 保留 ABS 调试命令，但主要工作流统一为 `工作模式 + 活动触手掩码 + 关系类型 + 控制使能`。
- 工作模式划分为单触手、双触手 1/2、双触手 3/4 和四触手；关系包括同向、镜像和中心对称。
- STOP 和 HOME 对当前活动组生效；单触手 POS 保留独立调试，协同模式使用统一输入再按安装关系变换。
- 触手 3/4 按触手 1/2 整体翻转 180°后的安装关系处理，每个触手最终仍经过自己的三电机方向表。

当前结果：

- 工作对象和控制关系已从分散命令收敛到统一分发层。
- 触手 4 的方向表已修正，但四触手所有方向组合仍需逐个使用小幅度命令验证，不能直接以大 BEND 做首次测试。

### 13.6 2026-07-13：虚拟按键误触和串口调试链路

现象：

- 手势滤波、帧数和时间窗叠加后，虚拟按键既难触发又可能误触；进入按键模式后还会干扰正常映射控制。
- VOFA 串口从 USART1 切换到 USART7 后，曾出现只能接收 H7 输出、H7 收不到上位机命令的情况。
- USB 转串口关闭或重新打开后，UART7 RX DMA 可能停止；插拔接收器后又恢复。

原因判断：

- 虚拟按键状态机与映射控制、RESTORE 等状态耦合过多，当前比赛调试阶段收益低于风险。
- 环形 DMA 写指针在计数器瞬间为 0 时可能得到缓冲区长度，若不归一化会破坏首尾判断；UART 错误回调还需要确保重新启动 RX DMA。

处理方法：

- 当前先关闭 H7 的手势虚拟按键触发，保留代码和串口查询，避免无意切入按键模式。
- VOFA UART 使用编译开关选择 USART1/USART7，发送统一通过句柄函数获取，不再写死 `huart1`。
- RX DMA 写位置等于缓冲区长度时归一化为 0；串口异常恢复逻辑只重启接收，不错误处理发送队列。

当前结果：

- USART7 可用于当前上位机通信；一次“完全无命令响应”最终通过重新插拔 USB 转串口恢复，说明硬件/驱动状态也是风险来源。
- 比赛前应验证串口断开重连，不应只验证上电后的第一次连接。

### 13.7 2026-07-13 至 2026-07-14：PC/AI 控制源隔离和上位机状态同步

现象：

- 上位机处于 PC 控制时，AI 新帧仍可能更新目标；上位机显示的模式与 H7 实际执行模式有时不一致。
- 上位机需要知道当前来源、使能、活动触手、在线/就绪/故障掩码和映射输入，但不需要显示全部电机内部变量。
- G4 状态中的 `online` 原本表示“最近是否收到 H7 命令”，H7 又据此决定是否发送命令，形成互相等待。

处理方法：

- 新增 `MSRC AI/PC` 控制源仲裁。切换来源时先 STOP 并关闭映射；PC 模式屏蔽 AI 和虚拟按键目标，但不阻塞 RESTORE/W25 后台任务。
- 新增 `MCTRL 0/1` 作为统一运动许可；`MVIRT` 只在 PC 来源且控制已启用时接受。
- 新增 `SNAP?` 返回控制来源、使能、模式、活动掩码、在线/就绪/故障掩码和当前映射输入；新增 `POS?` 返回四个触手相对 HOME 的位置。
- H7 的在线判断改为“已收到有效状态帧且状态年龄未超限”，不再依赖 G4 原始 `online` 位。

当前结果：

- PC 和 AI 目标已隔离，上位机可以通过 SNAP/POS 同步主要状态。
- 上位机编辑了新模式但未下发时，界面草稿可能与 H7 实际模式不同；启动前还需做到“下发模式并由 SNAP 确认后再启用”，该项仍待上位机完善。

### 13.8 2026-07-14 至 2026-07-15：READY、运行健康和一次性停止原因

现象：

- READY 条件同时用于启动和运行，短暂状态帧延迟会立即拒绝 MVIRT、清除 enable 并 STOP。
- 上位机因此出现 `ERR MVIRT NOT_READY`，下一帧又变成 `ERR MVIRT DISABLED`，实际机构并未发生危险却被频繁停机。
- `last_tx_status=2` 曾同时表示未就绪和 CAN 队列忙，诊断含义不清楚。

原因判断：

- 启动前必须严格确认坐标可信，但运行中不能把一次短暂 CAN/READY 抖动等同于坐标失效。
- READY、FAULT、TX_BUSY 和 CAN_TIMEOUT 是不同问题，必须分开处理。

处理方法：

- 启动 `MCTRL 1` 时继续严格检查：活动 G4 在线、状态新鲜、无 FAULT、RESTORE 完成且位置恢复有效。
- 运行中改为健康监测：短暂状态波动继续接收 MVIRT；FAULT 立即停止；真正停机后不自动重新启动。
- 增加一次性停止原因：`CAN_TIMEOUT`、`FAULT`、`RESTORE_LOST`、`ESTOP` 和 `GROUP_SYNC`，同一事件不重复刷屏。
- 安全 STOP 按 100 ms 间隔最多补发 5 轮，避免无限占用 CAN FIFO。

当前结果：

- 启动安全和运行容错已分离，PC 不再因单帧 READY 波动立刻退出。
- 为排查后续运动时假超时，当前代码暂时关闭了“CAN 状态超时自动停机”，只保留告警；FAULT 和人工急停仍需立即处理。恢复自动停机前必须先完成 13.10 的通信压力测试。

### 13.9 2026-07-15：断连重连时的坐标恢复原则

现象：

- 如果 G4 与 H7 断连期间仍在运动或被外力转动，H7 保存的最后 ACTUAL 已经不是 G4 的真实位置。
- 重连后若继续把 H7 旧 ACTUAL 写回 G4，会把错误坐标强行恢复到 G4，后续 HOME 和位置目标全部偏移。

最终原则：

- 正常运行时：G4 ACTUAL -> H7 -> W25Q64。
- H7 上电且能确认 G4 未发生未知运动时，才允许使用已验证的启动恢复流程。
- 运行中断连后重连：先 STOP，使用 G4 当前 ACTUAL 更新 H7 和 W25Q64，禁止用 H7 旧 ACTUAL 覆盖 G4。
- 重连只恢复坐标和状态，不自动续跑旧目标；用户重新确认后才能再次 `MCTRL 1`。

当前结果：

- 该原则已确定，但“区分首次上电与运行中掉线”“G4 当前 ACTUAL 的可信确认”和“重连后的写入顺序”仍需完整实机验证。

### 13.10 2026-07-15 至 2026-07-17：运动时 CAN 超时和四触手不稳定

现象：

- 单触手、双触手和四触手静止时状态正常，一运动就可能出现 `MSTOP reason=CAN_TIMEOUT` 或 `GROUP_SYNC`。
- 停止后所有触手又恢复在线，说明并非持续断线。
- 单纯增加 H7 ACK 等待时间、提高中断优先级或降低上位机刷新频率没有从根本上解决。

原因定位：

- G4 状态上报曾依赖 `HAL_GetTick()`/SysTick；高频电机中断和运行负载变化时，软件时间基准及调度不稳定，状态帧间隔被拉长。
- 四触手放大了状态帧、目标帧和确认帧的并发压力，H7 的严格超时把“状态延迟”误判为“节点掉线”。

处理方法：

- G4 状态上报改用固定定时器节拍分频，不再依赖 HAL SysTick 判断发送时机。
- 状态上报周期暂定 50 ms；H7 继续以最新状态时间戳判断，不要求每个目标都同步阻塞等待。
- 组命令序号按回绕方式比较，确认窗口放宽到 800 ms；发送失败时保持上一组有效目标，不生成半组新目标。
- 调整 CAN 中断优先级，避免状态收发长期被低优先级任务拖延。

当前结果：

- 改为固定定时器节拍后，实测“基本不卡”，这是本轮 CAN 稳定性改善最明显的修改。
- 50 ms 已能满足当前状态监测，没有必要立即改成 20 ms；四块 G4 全部烧录相同修复后再统一压力测试。

### 13.11 2026-07-17：W25Q64 保存失败与参数边界

现象：

- 重新烧录 H7 后有时需要重新 CANZERO 才显示 READY，表现得像 HOME/ACTUAL 丢失。
- 设置 `MCFG 32000 2500 ...` 或 `MCFG 30000 2500 ...` 时重复返回 `ERR MCFG_SAVE status=1`。

原因判断：

- 烧录内部 Flash 本身不会清除外部 W25Q64；问题更可能来自记录版本、有效标志、CRC、当前触手索引或启动时错误覆盖。
- 当前参数合法范围限制弯曲增益最大 `30000 q`、刚度增益最大 `2000 q`，`2500` 超出范围，因此保存被拒绝，不是 W25 容量溢出。

处理方法：

- HOME 和 ACTUAL 使用同一触手快照，保存时只覆盖确认更新的触手；旧有效记录在新记录校验成功前保留。
- 擦除和写入由任务状态机分步执行，避免一次长阻塞影响推理和 CAN。
- 参数写入前先做范围检查；需要更大刚度时，应先评估电机温升和绳索预紧，再同时修改范围和控制限幅，不能只放开 VOFA 检查。

当前结果：

- 当前可用默认值为 `bend=27000 q`、`stiff=2000 q`、`release_limit=30000 q`。
- W25 快照和非阻塞擦除已进入代码，但仍需做多次断电、烧录和记录区写满后的循环压力测试。

### 13.12 2026-07-18：当前尚未闭环的问题

#### 13.12.1 随机单触手持续弯曲且 STOP 无效

现象：

- 四触手运行中偶尔只有一个触手继续弯曲，其他触手不再响应；上位机姿态和 ACTUAL 仍持续变化，但弯曲输入值没有继续增大。
- 有时 CANSTOP 也不能立即让该触手停下，断电重连后 ACTUAL 又恢复正常。

当前判断：

- 不能只归因于上位机，因为 H7 显示输入不变而 G4 实际位置仍在变化。
- G4 的 STOP 当前经过 CAN 接收缓存和主循环任务后才真正关闭 PWM，若 STOP pending 被后续位置命令覆盖，或主循环被高频任务拖延，可能出现“状态帧仍在线，但命令没有及时执行”。
- 还需检查编码器 DMA 新鲜度；`valid=1` 不能代替“最近确实收到新角度”。

后续解决方案：

1. G4 增加独立的高优先级 STOP 锁存，STOP 不能被后续位置命令覆盖。
2. G4 增加编码器样本年龄看门狗，角度长期不更新时禁止继续位置环输出。
3. H7 不只确认 STOP 已入 CAN FIFO，还要等待 G4 状态确认 PWM 已关闭。
4. 增加“目标误差持续扩大”保护，防止方向错误时继续拉紧。

状态：待实现和实机验证，比赛前必须优先解决。

#### 13.12.2 上位机显示模式与 H7 实际模式不一致

现象：

- 在未启动时切换模式或锁定参数，上位机可能显示新的协同/四触手模式，但启动后 H7 返回的仍是 SOLO。

原因判断：

- 上位机界面保存的是未下发的模式草稿，周期 SNAP 又保留草稿显示；启动检查没有要求草稿先写入 H7 并得到确认。

后续解决方案：

- 启动按钮执行固定顺序：发送工作模式 -> 等待 SNAP 确认 -> 发送 `MCTRL 1`。
- 模式未确认时禁止发送 MVIRT；运行中点击三维触手只改变界面选择，不发送会停止活动组的 TSEL。

状态：上位机待修改，H7 的 SNAP 格式无需扩展。

### 13.13 截至 2026-07-18 的结论和验证顺序

已经确认可用：

- 新 H743VIT6 板上的 VL53、CNN、SPI4 W25Q64、USART7 和 CAN 基础链路。
- 单触手 POS、AI/PC 来源隔离、SNAP/POS 查询和多触手工作分发。
- G4 使用固定定时器节拍每 50 ms 上报状态后，运动时 CAN 卡顿明显改善。

当前优先级：

1. 先完成 G4 STOP 锁存和编码器新鲜度保护，复现并消除“单触手持续弯曲且无法停止”。
2. 四块 G4 全部使用同一版 50 ms 定时状态上报代码，依次做单触手、双触手、四触手压力测试。
3. 修正上位机模式草稿与 H7 实际模式的启动确认顺序。
4. 验证四触手方向表，特别是触手 4 的电机 1/2/3 收放线关系。
5. 做 W25Q64 多次断电、重新烧录和写满回绕测试。
6. 上述安全项通过后，再提高 BEND/STIFF 和抓取力度，不能用增益补偿尚未解决的方向或停止问题。

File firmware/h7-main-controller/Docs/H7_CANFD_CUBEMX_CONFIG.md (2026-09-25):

# H7 CAN FD CubeMX 配置说明

## 1. 目标

H7 主控板通过 FDCAN1 与 G4 电机从板通信。

当前通信目标：

```text
H7 -> G4:
  发送 0x120 CAN FD 位置命令帧
  一帧携带 motor0 / motor1 / motor2 三路目标位置

G4 -> H7:
  接收 0x180 CAN FD 状态帧
```

要求 H7 和 G4 的 CAN FD 位速率一致：

```text
Nominal bitrate: 1 Mbit/s
Data bitrate:    5 Mbit/s
Frame format:    CAN FD with BRS
```

## 2. 当前 H7 需要修改的原因

当前 H7 工程生成结果仍是 Classic CAN：

```c
hfdcan1.Init.FrameFormat = FDCAN_FRAME_CLASSIC;
hfdcan1.Init.NominalPrescaler = 10;
hfdcan1.Init.NominalTimeSeg1 = 13;
hfdcan1.Init.NominalTimeSeg2 = 2;
hfdcan1.Init.RxFifo0ElmtSize = FDCAN_DATA_BYTES_8;
hfdcan1.Init.TxElmtSize = FDCAN_DATA_BYTES_8;
GPIO_InitStruct.Speed = GPIO_SPEED_FREQ_LOW;
```

这会导致：

```text
1. 无法发送/接收 32 字节 CAN FD 帧
2. 无法使用 BRS 数据段加速
3. 与 G4 当前 CAN FD 配置不匹配
4. PD0/PD1 GPIO 速度过低，不适合 5Mbit/s 数据段
```

## 3. H7 FDCAN kernel clock

当前 H7 CubeMX 配置中 FDCAN 使用 PLL2 作为内核时钟。

当前生成配置：

```c
PeriphClkInitStruct.PLL2.PLL2M = 5;
PeriphClkInitStruct.PLL2.PLL2N = 64;
PeriphClkInitStruct.PLL2.PLL2P = 2;
PeriphClkInitStruct.PLL2.PLL2Q = 4;
PeriphClkInitStruct.PLL2.PLL2R = 4;
PeriphClkInitStruct.FdcanClockSelection = RCC_FDCANCLKSOURCE_PLL2;
```

CubeMX 当前计算出的 FDCAN 位时序显示：

```text
Nominal Time Quantum = 125 ns
```

说明当前 FDCAN kernel clock 用于位时序计算约为：

```text
1 / 125 ns = 8 MHz time quantum base after prescaler effect in current config
```

结合当前配置：

```text
Nominal Prescaler = 10
Nominal bit time = 2000 ns
Nominal bitrate = 500 kbit/s
```

可反推出当前 FDCAN kernel clock 为：

```text
80 MHz
```

所以 H7 不能照抄 G4 的 85MHz 位时序参数，但最终的仲裁段和数据段 bitrate 必须与 G4 一致。

## 4. CubeMX 中 FDCAN1 参数

在 `Connectivity -> FDCAN1` 中修改。

### 4.1 基本模式

```text
Frame Format:          FD mode with BitRate Switching
Mode:                  Normal mode
Auto Retransmission:   Enable
Transmit Pause:        Disable
Protocol Exception:    Disable
```

含义：

```text
FD mode with BitRate Switching:
  使用 CAN FD，并在数据段切换到高速 bitrate。

Auto Retransmission:
  发送失败、仲裁丢失或错误后自动重发。

Transmit Pause:
  第一版关闭，避免额外发送间隔影响轨迹下发。

Protocol Exception:
  第一版关闭，保持协议行为简单。
```

### 4.2 仲裁段 Nominal Bit Timing

目标：

```text
Nominal bitrate = 1 Mbit/s
```

H7 当前 FDCAN kernel clock 约为 80 MHz，推荐：

```text
Nominal Prescaler:        5
Nominal Sync Jump Width:  3
Nominal Time Seg1:        12
Nominal Time Seg2:        3
```

计算：

```text
80 MHz / 5 / (1 + 12 + 3) = 1 MHz
```

采样点：

```text
(1 + TimeSeg1) / (1 + TimeSeg1 + TimeSeg2)
= (1 + 12) / 16
= 81.25%
```

### 4.3 数据段 Data Bit Timing

目标：

```text
Data bitrate = 5 Mbit/s
```

推荐：

```text
Data Prescaler:        1
Data Sync Jump Width:  3
Data Time Seg1:        12
Data Time Seg2:        3
```

计算：

```text
80 MHz / 1 / (1 + 12 + 3) = 5 MHz
```

## 5. Message RAM 配置

CAN FD 32 字节帧必须把 Rx/Tx element size 改大。

推荐配置：

```text
Std Filters Nbr:          1 或 8
Ext Filters Nbr:          0

Rx FIFO0 Elements Nbr:    8
Rx FIFO0 Element Size:    32 bytes

Rx FIFO1 Elements Nbr:    0
Rx FIFO1 Element Size:    32 bytes 或默认

Tx FIFO Queue Elements:   8
Tx Element Size:          32 bytes
Tx FIFO Queue Mode:       FIFO mode
```

生成后应看到：

```c
hfdcan1.Init.RxFifo0ElmtsNbr = 8;
hfdcan1.Init.RxFifo0ElmtSize = FDCAN_DATA_BYTES_32;
hfdcan1.Init.TxFifoQueueElmtsNbr = 8;
hfdcan1.Init.TxElmtSize = FDCAN_DATA_BYTES_32;
```

如果仍是：

```c
FDCAN_DATA_BYTES_8
```

则 H7 无法正确收发 32 字节 CAN FD 帧。

## 6. GPIO 配置

当前 H7 使用：

```text
PD0 -> FDCAN1_RX
PD1 -> FDCAN1_TX
```

CubeMX 中把 PD0/PD1 的 GPIO speed 改为：

```text
Very High
```

生成后应看到：

```c
GPIO_InitStruct.Speed = GPIO_SPEED_FREQ_VERY_HIGH;
```

不要保持：

```c
GPIO_SPEED_FREQ_LOW
```

5Mbit/s 数据段下 GPIO 低速边沿可能导致通信不稳定。

## 7. NVIC 配置

当前 H7：

```text
FDCAN1_IT0_IRQn priority = 5
```

第一版可以保持。

H7 是主控，不运行 G4 那种高频电流环，因此 FDCAN 中断优先级可以比 G4 稍高。但仍建议中断中只收帧缓存，不做复杂轨迹规划。

## 8. 生成后 fdcan.c 检查清单

CubeMX 生成代码后，检查 `H743VIT6/Core/Src/fdcan.c`。

应满足：

```c
hfdcan1.Init.FrameFormat = FDCAN_FRAME_FD_BRS;
hfdcan1.Init.Mode = FDCAN_MODE_NORMAL;
hfdcan1.Init.AutoRetransmission = ENABLE;

hfdcan1.Init.NominalPrescaler = 5;
hfdcan1.Init.NominalSyncJumpWidth = 3;
hfdcan1.Init.NominalTimeSeg1 = 12;
hfdcan1.Init.NominalTimeSeg2 = 3;

hfdcan1.Init.DataPrescaler = 1;
hfdcan1.Init.DataSyncJumpWidth = 3;
hfdcan1.Init.DataTimeSeg1 = 12;
hfdcan1.Init.DataTimeSeg2 = 3;

hfdcan1.Init.RxFifo0ElmtsNbr = 8;
hfdcan1.Init.RxFifo0ElmtSize = FDCAN_DATA_BYTES_32;
hfdcan1.Init.TxFifoQueueElmtsNbr = 8;
hfdcan1.Init.TxElmtSize = FDCAN_DATA_BYTES_32;
```

GPIO 应满足：

```c
GPIO_InitStruct.Speed = GPIO_SPEED_FREQ_VERY_HIGH;
GPIO_InitStruct.Alternate = GPIO_AF9_FDCAN1;
```

## 9. 与 G4 配置对齐

G4 当前配置：

```text
FDCAN kernel clock after divider: 85 MHz
Nominal: 1 Mbit/s
Data:    5 Mbit/s
FD+BRS:  enabled
```

H7 当前推荐配置：

```text
FDCAN kernel clock: 80 MHz
Nominal: 1 Mbit/s
Data:    5 Mbit/s
FD+BRS:  enabled
```

注意：

```text
H7 和 G4 的具体 Prescaler/TimeSeg 可以不同
但最终 Nominal bitrate 和 Data bitrate 必须一致
```

## 10. H7 发送 0x120 命令帧

H7 发给 G4：

```text
ID:      0x120
Format:  CAN FD + BRS
DLC:     32 bytes
```

Payload：

```text
byte0      protocol_version = 1
byte1      command = 0x01 position / 0x02 stop
byte2      flags
byte3      motor_mask = 0x07
byte4      seq
byte5..7   reserved
byte8..11   motor0_target_q int32 little-endian
byte12..15  motor1_target_q int32 little-endian
byte16..19  motor2_target_q int32 little-endian
byte20..31  reserved
```

位置缩放：

```text
target_q = motor_target_rad * 100000
```

常用 flags：

```text
ENABLE + APPLY = 0x09
ENABLE + APPLY + RELATIVE = 0x0D
STOP = 0x02
```

## 11. H7 接收 0x180 状态帧

G4 返回给 H7：

```text
ID:      0x180
Format:  CAN FD + BRS
DLC:     32 bytes
```

Payload：

```text
byte0    protocol_version
byte1    board_id
byte2    online
byte3    control_word
byte4..5 rx_count low16
byte6..7 tx_count low16
byte8..11 error_count uint32
byte12   pwm_started_mask
byte13   last_relative_seq
byte14   last_relative_seq_valid
byte15   position_pending
byte16   last_position_seq
byte17   last_position_flags
byte18   last_position_motor_mask
byte19   last_position_command
byte20..31 reserved
```

## 12. 调试顺序

1. 先只观察 G4 状态帧：

```text
是否能看到 0x180
是否为 CAN FD + BRS
DLC 是否为 32
```

2. H7 发送无动作位置帧：

```text
ID 0x120
flags = 0
motor_mask = 0x07
```

预期：

```text
G4 0x180 rx_count 增加
G4 error_count 不增加或只因 flags 不满足而按预期增加
电机不动
```

3. H7 发送 stop 帧：

```text
command = 0x02
flags = 0x02
motor_mask = 0x07
```

4. H7 发送小幅绝对位置命令：

```text
command = 0x01
flags = 0x09
motor_mask = 0x07
```

先使用接近当前位置的小目标，避免触手大幅抽动。

## 13. 注意事项

1. H7 和 G4 必须使用相同的 CAN FD 物理层设置：

```text
Nominal 1M
Data 5M
BRS ON
终端电阻正确
CAN FD 收发器支持 5M 数据段
```

2. 电脑 CAN 分析器也要配置为：

```text
CAN FD
Nominal 1M
Data 5M
BRS ON
```

3. 如果总线能看到错误帧，优先检查：

```text
波特率
GPIO speed
收发器是否支持 CAN FD
终端电阻
H7/G4 是否共地
Rx/Tx element size 是否为 32 bytes
```

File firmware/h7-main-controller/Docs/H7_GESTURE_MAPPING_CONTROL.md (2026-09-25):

# H7 手势到三线触手映射控制逻辑

## 1. 文档目的

本文档用于记录 H7 主控侧的手势映射控制逻辑，方便后续把 VL53 传感器数据、AI 推理结果和三电机位置控制连接起来。

当前控制链路为：

```text
VL53 8x8 距离/CNH 数据
  -> H7 手部位置与张握程度判断
  -> 归一化虚拟控制量 x / y / bend / stiffness
  -> 三根绳子的拉紧量 pull0 / pull1 / pull2
  -> 三台电机绝对位置 target0 / target1 / target2
  -> CAN FD 一帧同步发送给 G4
  -> G4 三电机位置伺服执行
```

G4 只负责三电机闭环执行，不理解触手模型。触手映射、手势解释、轨迹规划和 CAN 目标生成都放在 H7。

## 2. 输入变量定义

H7 映射层使用四个虚拟输入：

```text
x           手在传感器平面内的 X 方向，范围 -100~100。
y           手在传感器平面内的 Y 方向，范围 -100~100。
bend        弯曲程度，范围 0~100。
stiffness   刚度/预紧程度，范围 0~100。
```

含义如下：

```text
x/y:
  只决定触手弯曲方向，不直接决定弯曲幅度。

bend:
  决定触手卷曲/弯曲程度。

stiffness:
  决定三根绳子的共同拉紧量，用于改变整体预紧和刚度。
```

注意：手在平面内离中心越远，并不表示触手弯得越厉害。平面位置只用于生成方向，弯曲幅度由张握程度控制。

## 3. VL53 和 AI 输出的使用方式

VL53 提供手部空间位置和距离信息：

```text
hand_x / hand_y:
  根据 8x8 距离阵列中手部区域的中心位置计算。

hand_z:
  根据手部区域的平均距离或加权距离计算。
```

AI 推理输出手部张开程度：

```text
openness_score:
  0   = 接近握拳
  100 = 接近张开
```

如果控制上使用“握紧程度”作为弯曲量，则需要转换：

```text
grip = 100 - openness_score
bend = grip
```

如果后续模型直接输出“握紧程度”，则可以直接使用：

```text
bend = grip_score
```

距离 `hand_z` 用于刚度控制：

```text
hand_z 近  -> stiffness 增大，三根绳子共同拉紧，触手更硬。
hand_z 远  -> stiffness 减小，三根绳子共同放松，触手更软。
```

## 4. 方向映射规则

手部平面位置先转换为归一化方向输入：

```text
x = normalize(hand_x)
y = normalize(hand_y)
```

为了避免手在中心附近轻微抖动导致方向突变，需要使用中心死区：

```text
if sqrt(x*x + y*y) < direction_deadband:
    不更新弯曲方向
```

中心死区内推荐保持上一帧有效方向，而不是把方向强行置零。这样可以避免触手目标方向在中心附近来回跳变。

方向半径只用于判断方向是否可靠：

```text
半径很小：方向无效或保持上一方向。
半径中等：方向逐步更新。
半径较大：方向稳定采用当前手部方向。
```

方向半径不参与 `bend` 的计算，避免手在平面内轻微移动就改变弯曲幅度。

## 5. 三根绳子的空间方向

三根绳子按 120 度分布，当前使用整数近似方向向量：

```text
cable0 = (100,   0)
cable1 = (-50,  87)
cable2 = (-50, -87)
```

每根绳子在当前手部方向上的投影为：

```text
projection_i = (x * cable_x[i] + y * cable_y[i]) / 100
projection_i = clamp(projection_i, -100, 100)
```

投影含义：

```text
projection_i > 0:
  当前弯曲方向更接近第 i 根绳子的方向，该绳子需要更多拉紧。

projection_i < 0:
  当前弯曲方向远离第 i 根绳子的方向，该绳子需要相对放松。
```

三根 120 度方向向量近似满足：

```text
projection0 + projection1 + projection2 ~= 0
```

因此差动弯曲不会明显改变三根绳子的平均拉紧量，平均拉紧量由 `stiffness` 单独控制。

## 6. 拉绳量计算

H7 先在“拉绳空间”计算目标。

共同拉紧量：

```text
common_pull_q = stiff_gain_q * stiffness / 100
```

方向弯曲拉紧量：

```text
bend_pull_q[i] = bend_gain_q * bend * projection_i / 10000
```

每根绳子的最终拉紧量：

```text
pull_q[i] = common_pull_q + bend_pull_q[i]
```

这里的 `pull_q` 单位为 `0.01rad`，表示等效到电机侧的位置变化量。

约定：

```text
pull_q > 0 表示收绳/拉紧。
pull_q < 0 表示放绳/放松。
```

## 7. 拉绳量到电机目标

当前机械方向约定：

```text
电机正转 = 放长绳子
电机反转 = 缩短绳子
```

因此拉绳量到电机目标需要取反：

```text
target_q[i] = neutral_q[i] - pull_q[i]
```

其中：

```text
neutral_q[i]:
  第 i 台电机的中立位置，单位 0.01rad。
  通常对应触手伸直、绳子刚好拉紧的参考位置。

target_q[i]:
  发送给 G4 的第 i 台电机绝对位置目标，单位 0.01rad。
```

最终目标需要限幅：

```text
target_q[i] = clamp(target_q[i], target_min_q, target_max_q)
```

## 8. CAN FD 下发

H7 每次生成新的三电机位置目标后，通过 CAN FD 一帧同步发送给 G4。

位置目标使用 `int32` 小端格式：

```text
target_q = target_rad * 100
```

一帧同时包含三台电机目标：

```text
motor0_target_q
motor1_target_q
motor2_target_q
```

三台电机必须作为一个同步动作组下发，不建议单独覆盖其中一路目标。

## 9. 当前代码对应关系

当前 H7 代码中，虚拟输入接口为：

```c
MotorControl_SetVirtualInput(x, y, bend, stiffness);
```

对应文件：

```text
H743VIT6/Core/motor_control_app/motor_control_app.c
H743VIT6/Core/motor_control_app/motor_control_app.h
```

当前核心映射关系为：

```text
input_x/input_y
  -> projection_i
  -> bend_pull_q[i]

stiffness
  -> common_pull_q

common_pull_q + bend_pull_q[i]
  -> pull_q[i]

neutral_q[i] - pull_q[i]
  -> target_q[i]
```

## 10. 推理控制触发时机

AI 推理不应该放在中断中，也不应该在主循环中无条件反复运行。

推荐触发条件：

```text
VL53_App_Task() 读取到一帧新的有效数据
  -> 标记 new_frame
  -> 主循环中的手势控制任务消费 new_frame
  -> 构造 AI 输入
  -> 调用 GestureAI_Run()
  -> 更新 x/y/bend/stiffness
  -> 必要时发送新的三电机目标
```

第一版建议推理频率跟随 VL53 新帧频率，例如 10Hz。G4 侧位置环负责平滑执行，不需要 H7 在没有新输入时重复发送同一个目标。

## 11. 调试观察量

H7 侧建议观察：

```text
x
y
bend
stiffness
pull_q[0..2]
target_q[0..2]
CAN 发送次数
CAN 最后状态
```

G4 侧建议观察：

```text
三电机实际多圈位置
三电机目标位置
三电机速度
三电机 iq/id
CAN 命令接收计数
CAN 状态帧
```

## 12. 注意事项

1. 平面位置只控制方向，不控制弯曲幅度。
2. 张握程度控制弯曲幅度。
3. 距离控制刚度/预紧。
4. 三根绳子的差动量应尽量保持均值为 0。
5. 三根绳子的共同量只由 `stiffness` 控制。
6. 电机正转是放绳，收绳目标需要让电机位置减小。
7. 三台电机目标必须一帧同步下发，避免触手形态被单路目标覆盖破坏。
8. AI 推理只在 VL53 新帧到来后运行，不能放进高频中断。
9. 中心死区内不要让方向乱跳，应保持上一有效方向或缓慢回中。
10. 后续如果加入轨迹规划，应在 H7 侧对 `x/y/bend/stiffness` 或 `target_q[3]` 做斜坡，而不是让 G4 理解触手模型。

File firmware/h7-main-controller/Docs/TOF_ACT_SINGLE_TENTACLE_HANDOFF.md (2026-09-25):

# 基于VL53L8CH与ACT的单触手自主包裹方案

## 1. 文档目的

本文档用于交接单触手ACT自主抓取功能的设计方案，说明系统目标、输入数据、示教采集、LeRobot数据集格式、ACT训练样本、H7部署流程和验证标准。

本文描述的是下一阶段设计，当前工程尚未完成ACT采集、训练和部署代码。现有手势CNN、映射控制和多触手控制代码不能直接视为ACT实现。

## 2. 最终实验目标

使用一路VL53L8CH观察触手工作空间，控制一块G4上的三台拉索电机，使单根触手从初始位置自主运动并包裹塑料瓶。

演示目标如下：

1. ACT模式启动后，触手保持在规定初始位置。
2. 操作者可在传感器视野和触手可达范围内随机放置塑料瓶。
3. 模型根据VL53L8CH时序数据和电机状态判断瓶子位置及触手状态。
4. 模型连续输出三台电机的位置目标，使触手逐步接近并包裹瓶子。
5. 包裹完成后保持最终位置1~2秒。

“任意摆放”仅表示训练数据覆盖范围内的左右、远近和倾斜变化，不表示能够处理传感器视野外、触手不可达或训练分布之外的任意位置。

## 3. 当前确定的技术边界

第一版遵循以下约束：

- 只控制一根触手和三台电机。
- VL53L8CH采样频率目标为20Hz。
- 不使用摄像头作为在线输入。
- 不在ACT启动时单独采集背景。
- 不进行背景中值估计、背景差分和背景前景分割。
- 不生成三维重建结果作为ACT输入。
- 不使用伪彩色视频参与训练。
- ACT使用10个固定CNH距离区间，中心距离约覆盖113~450mm。
- ACT直接使用传感器原始特征和电机状态学习“等待、接近、包裹、保持”。
- 第一版保持每区域一个主要目标；多目标输出只作为后续遮挡优化项。
- VL53L8CH与H7使用I2C1 Fast Mode Plus，目标速率为1MHz。
- ACT数据通过USART1以2Mbps、8N1和DMA发送；UART7继续用于原有VOFA控制。
- `nb_spads_enabled`不进入ACT输入，可关闭其结果输出以减少I2C传输量；这不会关闭传感器内部SPAD。

## 4. 系统数据流

```text
VL53L8CH产生当前帧
        |
        v
H7整理18通道ToF特征
        |
        +---- 请求并读取G4三电机状态
        |
        v
按sample_seq组成同一时刻的observation
        |
        +---- 示教阶段：记录H7最终发送命令action
        |
        `---- 推理阶段：ACT预测未来动作序列
                          |
                          v
                 H7执行安全限幅
                          |
                          v
                 仅发送当前一步给G4
```

H7是数据对齐主节点。每个VL53采样周期生成一个`sample_seq`，电机状态、观测和随后发送的动作都必须与该序号关联。

## 5. 单帧ToF输入

### 5.1 数据形状

单帧传感器输入固定为：

```text
observation.tof: float32 [18, 8, 8]
```

每个通道的`[row, column]`都对应VL53L8CH的同一个测距区域。

### 5.2 通道定义

| 通道 | 名称 | 数据含义 | 主要作用 |
|---:|---|---|---|
| 0 | `distance_mm` | 当前主要目标距离，单位mm | 提供瓶子、触手和环境的绝对空间深度 |
| 1 | `valid_mask` | 0表示无效，1表示有效 | 防止无效的0距离被理解为近距离目标 |
| 2 | `target_status` | 传感器目标状态码的固定映射值 | 表示弱信号、误差过大、多目标干扰等测距质量 |
| 3 | `target_count` | 当前区域检测到的目标数量 | 区分无目标和存在反射目标；单目标配置下通常为0或1 |
| 4 | `signal_amplitude` | 有效返回信号强度 | 判断反射质量，辅助处理透明瓶、标签和遮挡 |
| 5 | `ambient_ir` | 环境红外强度 | 判断阳光或红外干扰对测距质量的影响 |
| 6 | `reflectance` | 传感器估计反射率 | 辅助区分瓶体、标签、触手和背景表面 |
| 7 | `range_sigma` | 距离结果的不确定度估计 | 让模型降低对高误差测距区域的依赖 |
| 8~17 | `cnh_bin_0~9` | 十个固定深度区间内的CNH响应 | 保留不同深度上的反射分布和弱反射信息 |

### 5.3 各通道注意事项

#### 当前距离

距离提供主要几何信息。无效区域的距离应填固定值，并通过`valid_mask`明确标记，不能把无效数据直接当成真实的`0mm`目标。

#### 有效掩码

有效掩码只表示当前区域是否具有可使用的测距结果。它不代替`target_status`，因为状态码还包含更具体的失败或降级原因。

#### target_status

状态码是类别，不是连续物理量，不能认为数值越大测距越可靠。数据转换脚本必须使用固定映射，例如映射为“有效、降级可用、无效”，训练和H7部署必须使用完全相同的规则。

#### target_count

如果传感器配置为每区域一个目标，该通道只能提供0或1。未来若启用两个目标，必须同时增加第二目标的距离、状态、信号、反射率和sigma，不能只增加第二目标距离。

#### signal amplitude

信号强度反映返回红外光子的强弱，受距离、材质和表面角度影响。透明塑料瓶可能出现信号较弱或不稳定，使用带磨砂表面、纸质标签或套筒的瓶子会更可靠。

#### ambient IR

该数据表示环境红外，不等同于普通可见光亮度。它主要用于帮助模型判断测距质量是否受到阳光、红外灯或其他ToF设备干扰。

#### reflectance

反射率是传感器估计值，不是物体固定不变的材料参数。距离、入射角和表面曲率变化都会影响该值，因此它只能作为辅助特征。

#### range sigma

sigma是传感器估计的不确定度，不是已知的真实误差。数值较大通常表示该区域测距不稳定。

#### CNH

ACT使用10个CNH区间覆盖触手实际工作距离。VL53L8CH每个CNH bin约间隔37.5mm，ACT使用的中心距离约为：

```text
113, 150, 188, 225, 263, 300, 338, 375, 413, 450 mm
```

区间边界和精确中心值应从最终传感器配置导出，并在采集固件、数据集元数据、训练脚本和H7部署代码中保持一致。CNH表示各深度区间的响应强弱，不等同于十个独立目标。第一版不建立单独CNH网络分支，而是直接作为10个`8x8`输入通道。

### 5.4 现有手势20通道与ACT 18通道的区别

当前H7手势CNN已经实现的20通道为：

```text
0       相对手掌中心距离
1       绝对距离
2       有效掩码
3       手掌前景掩码
4       status是否为5或9
5       target数量
6~13    CNH八个区间
14      手掌中心X
15      手掌中心Y
16      手掌中心距离Z
17      手掌前景区域数量
18      手掌包围框宽度
19      手掌包围框高度
```

其中手掌中心、前景数量和包围框都依赖“最近前景是手掌”的假设，适合手势张握识别，不适合同时包含瓶子、触手、操作者手和遮挡的ACT抓取场景。

ACT方案删除以下8个手势专用特征：

```text
相对手掌中心距离
手掌前景掩码
手掌中心X/Y/Z
手掌前景区域数量
手掌包围框宽度/高度
```

同时增加4个传感器物理特征：

```text
signal amplitude
ambient IR
reflectance
range sigma
```

ACT保留8个通用传感器物理特征，并使用10个CNH通道，因此总输入为`8 + 10 = 18`通道。

为了不改变原手势CNN，传感器统一采集从`start_bin=3`开始的11个CNH bin：ACT使用前10个，原手势CNN使用偏移3之后的8个。这样手势模型仍看到原来的`start_bin=6`至`bin=13`，无需重新训练。新18通道是ACT采集与训练方案，尚未写入当前H7固件；实现时需要同步修改VL53输出配置、采集记录、PC转换脚本和ACT预处理。

## 6. 电机状态输入

### 6.1 数据形状

```text
observation.state: float32 [3]
```

### 6.2 状态定义

| 索引 | 数据 | 作用 |
|---:|---|---|
| 0~2 | 三电机当前实际位置`actual` | 描述触手当前姿态 |

位置统一使用H7拉线坐标：

```text
正数：收线
负数：放线
1q = 0.01rad电机机械角
位置零点：每个电机的HOME
```

不额外输入上一帧位置、H7命令位置、速度或位置误差。连续12帧`actual`已经包含位置变化历史；差分速度容易放大CAN延迟和时间抖动，命令与延迟到达的`actual`直接相减也可能产生不真实误差。

H7本周期将要发送的命令位置属于训练标签`action[k]`，不能同时放入`observation.state[k]`，否则会把答案泄漏给模型，并造成部署时缺少该输入。

## 7. 动作数据

### 7.1 数据形状

```text
action: float32 [3]
```

### 7.2 动作语义

```text
action[0]: 电机1相对HOME的位置目标
action[1]: 电机2相对HOME的位置目标
action[2]: 电机3相对HOME的位置目标
```

动作必须记录H7完成方向统一、工作范围限制和同步缩放后，真正发送给G4的位置目标。不能记录H7限幅前的中间值，否则训练标签与真实执行动作不一致。

`action[k]`的严格时间含义是：

```text
先取得observation[k]
再计算并发送action[k]
```

如果该次CAN发送失败，未被G4执行的命令不能作为有效标签。该帧应标记为无效，或者把`action[k]`保持为G4仍在执行的上一条成功命令。

## 8. Episode采集流程

一段episode表示一次完整抓取过程，长度允许变化。

推荐流程：

```text
触手进入固定初始状态
        |
        v
无瓶子，随机等待0.5~3秒
        |
        v
在随机位置和角度放入瓶子
        |
        v
通过现有控制方式使触手逐步接近并包裹瓶子
        |
        v
包裹完成后保持1~2秒
        |
        v
结束并标记成功或失败
```

随机等待时间用于防止模型根据固定时间启动，而不是根据传感器中的瓶子信息启动。等待阶段的动作目标保持在初始位置。

操作者放置瓶子的手可能进入VL53视野，因此训练数据中应包含手进入、瓶子放下、手离开的完整过程。否则模型可能把操作者的手误认为抓取目标。

## 9. LeRobot风格数据集目录

第一版只使用两个目录，不生成`videos`：

```text
tof_act_dataset/
|-- data/
|   `-- chunk-000/
|       `-- file-000.parquet
`-- meta/
    |-- info.json
    |-- stats.json
    |-- tasks.parquet
    `-- episodes/
        `-- chunk-000/
            `-- file-000.parquet
```

该职责划分借鉴LeRobot的数据和元数据结构，但不要求把VL53数据转换成摄像头视频。

## 10. data逐帧字段

`data/chunk-xxx/file-xxx.parquet`中的每一行对应一个20Hz采样时刻。

| 字段 | 类型和形状 | 含义 |
|---|---|---|
| `observation.tof` | `float32 [18,8,8]` | 当前VL53多通道输入 |
| `observation.state` | `float32 [3]` | 当前三电机实际位置`actual` |
| `action` | `float32 [3]` | 本帧观测后H7实际发送的三电机位置命令 |
| `timestamp` | `float32` | 当前episode内的秒时间戳 |
| `episode_index` | `int64` | 所属episode编号 |
| `frame_index` | `int64` | 当前episode内帧编号 |
| `sample_seq` | `int64` | H7生成的同步采样序号 |
| `task_index` | `int64` | 任务编号，第一版固定为包裹塑料瓶 |
| `next.done` | `bool` | 当前帧是否为episode最后一帧 |

原始采集时由H7通过USART1 DMA发送紧凑二进制`ACT_FRAME`，PC在内存中暂存当前episode。用户确认保存后，PC再写入数据文件；选择删除时直接丢弃本次缓存。H7不生成Parquet，也不在采样过程中写SD卡。

## 11. meta字段

### 11.1 info.json

至少记录：

```text
数据集版本
fps = 20
总episode数量
总帧数
observation.tof形状与18个通道名称
observation.state形状与3个电机实际位置名称
action形状、单位和方向定义
CNH十个区间边界和中心距离
target_status映射规则
```

### 11.2 stats.json

保存训练数据的归一化统计：

```text
mean
std
min
max
```

连续物理量使用固定统计值归一化；掩码保持0和1；状态码使用固定映射；CNH使用固定裁剪和固定归一化参数。

不能对每帧单独做最大最小归一化，否则同一个数值在不同帧中的含义会变化。

### 11.3 tasks.parquet

第一版任务可以只定义一个：

```text
task_index = 0
task = "wrap the plastic bottle"
```

第一版模型不需要语言指令输入，该字段主要用于兼容数据集组织和后续扩展。

### 11.4 episodes元数据

每个episode记录：

```text
episode_index
开始与结束数据索引
总帧数
持续时间
success
瓶子左右区域
瓶子远近区域
瓶子倾斜类别
失败原因
备注
```

不保存背景距离和背景signal，因为最终方案不执行单独背景采集。

## 12. ACT训练样本构造

完整episode保存在数据集中，训练加载器再通过滑动窗口构造样本。

第一版窗口定义：

```text
最近12帧observation -> 未来10帧action
```

在20Hz下：

```text
12帧观测 = 0.60秒历史
10帧动作 = 0.50秒未来目标
```

训练输入：

```text
tof_history:   [12,18,8,8]
state_history: [12,3]
```

训练标签：

```text
action_chunk: [10,3]
```

接近episode结尾、未来动作不足10帧时，使用最后动作补齐并生成padding mask，损失函数不能把无效填充部分当成新动作。

## 13. 模型建议

第一版使用面向H7部署的Tiny ToF-ACT：

```text
18通道8x8 ToF
    -> 小型共享2D CNN
    -> 每帧ToF特征

3维电机实际位置
    -> 小型MLP
    -> 每帧状态特征

两类特征融合
    -> 12帧时间序列
    -> Tiny Transformer
    -> 未来10帧三电机目标
```

建议初始规模：

```text
d_model = 64
heads = 4
encoder_layers = 3
decoder_layers = 1
feedforward_dim = 128
action_chunk = 10
```

参数量目标约10万~30万。先完成PC端训练和FP32验证，再根据H7资源执行INT8量化。不要一开始同时加入多目标、三维重建、VLA和复杂接触估计。

## 14. H7推理流程

推理时ACT连续运行，不执行背景采集状态机。

```text
进入ACT模式
    -> 验证单触手ONLINE、READY且无FAULT
    -> 保持当前安全目标
    -> 清空12帧历史
    -> 连续接收VL53和电机状态
    -> 历史不足时复制最早有效帧并记录有效长度
    -> ACT预测未来10帧动作
    -> 只执行动作序列中的当前一步
    -> 下一帧重新观测和预测
```

模型通过训练数据学习：

```text
没有瓶子：保持初始位置
瓶子出现：开始接近和包裹
包裹完成：保持最终位置
```

H7不能一次性执行完整10帧动作序列，否则失去闭环纠偏能力。

## 15. 安全边界

ACT只能产生候选位置目标，以下保护仍由H7和G4负责：

- 单电机绝对位置范围。
- 三拉索关联缩放限制。
- 最大速度限制。
- CAN状态和故障处理。
- G4位置环和堵转保护。
- 人工急停。
- ACT输出变化率限制。

模型输出不能绕过现有安全限制。保持状态表示继续维持最后位置目标，不等同于发送STOP并释放位置环。

当前系统曾出现个别触手持续弯曲且STOP无法及时生效的现象。在该问题完成复现和验证前，不允许直接进行无人值守ACT抓取实验。

## 16. 数据采集覆盖范围

建议先定义明确的可达工作区，再进行分层采样：

```text
左右位置：至少5档
远近位置：至少4档
倾斜角度：至少3档
```

形成约60种基础摆放组合。每种组合至少示教3次，并补充边界位置和失败样本。

数据集必须包含：

- 不同的随机等待时间。
- 操作者放瓶和手离开的过程。
- 成功包裹轨迹。
- 接近但未包住的失败轨迹。
- 瓶子位于工作区边缘的轨迹。
- 少量传感器无效点和信号波动。

训练集和验证集必须按完整episode划分，不能把同一个抓取episode的帧随机分到训练集和验证集。

推荐把部分瓶子位置组合完整留作测试集，用于验证模型是否能够泛化到未参与训练的摆放位置。

## 17. 验证指标

### 17.1 数据质量

- 实际采样频率及抖动。
- VL53帧、电机状态和动作的`sample_seq`一致率。
- 无效测距比例。
- CAN电机状态超时比例。
- action是否全部为H7实际发送值。

### 17.2 离线模型

- 三电机动作MAE。
- 动作方向正确率。
- 动作变化率和预测抖动。
- 不同瓶子区域的分段误差。
- 无瓶子期间的误动作率。
- 完成阶段保持稳定性。

### 17.3 实物实验

- 抓取成功率。
- 从瓶子出现到开始运动的延迟。
- 从开始运动到完成包裹的时间。
- 工作区边缘成功率。
- 触手遮挡后是否继续稳定运行。
- 是否出现持续收线、超范围或无法停止。

## 18. 推荐实施顺序

1. 固定单触手、初始位置和安全工作范围。
2. 完成20Hz的VL53与G4电机状态同步记录。
3. 定义并验证18通道转换结果，同时回归验证原手势CNN。
4. 完成H7紧凑二进制`ACT_FRAME`发送格式。
5. 完成PC端二进制到LeRobot双目录数据集的转换脚本。
6. 采集少量episode，检查时序和动作标签。
7. 采集正式训练、验证和测试数据。
8. 在PC训练Tiny ToF-ACT并进行离线回放。
9. 导出ONNX，先在PC验证一致性。
10. 生成Cube.AI代码并在H7验证单帧输入输出。
11. 先断开电机，只观察ACT预测目标。
12. 低速度、低范围接入单触手闭环。
13. 完成安全验证后再进行完整瓶子包裹演示。

## 19. 暂不实施的内容

以下功能不进入第一版：

- 每次ACT启动时采集背景并取时间中值。
- 背景距离差分和背景signal差分。
- 伪彩色距离视频。
- VL53到三维占据网格的重建模型。
- 在线摄像头输入。
- 三目标输入。
- 多触手ACT协同。
- VLA语言控制。

这些项目只能在第一版单触手抓取稳定后，依据实际失败原因逐项增加。

## 20. 交接时必须保持一致的定义

```text
采样频率：20Hz
ToF单帧输入：[18,8,8]
电机单帧状态：[3]，仅包含三电机actual
历史长度：12帧
动作块长度：10帧
动作维度：3
位置单位：1q = 0.01rad
位置方向：正数收线，负数放线
位置基准：相对HOME
ACT CNH数量：10个固定距离区间，中心约113~450mm
传感器CNH采集：start_bin=3，共11个bin
手势CNN CNH：从统一结果偏移3，继续使用原8个bin
I2C1：100MHz内核时钟，1MHz Fast Mode Plus，TIMINGR=0x00A2192B
USART1：2Mbps、8N1、DMA，用于ACT命令和二进制数据
数据目录：data + meta
```

任何一项发生变化，都必须同步修改采集固件、转换脚本、训练配置、模型导出和H7推理预处理，不能只修改其中一处。

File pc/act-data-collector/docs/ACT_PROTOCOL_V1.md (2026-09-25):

# ACT USART1 混合协议 V1

## 1. 当前协议基线

本文件与 `H743VIT6_ACT/Core/act_stream/act_stream.c` 第一阶段实现一致：

```text
PC -> H7：ASCII命令，以CRLF结束
H7 -> PC：带长度和CRC32的二进制包
```

当前阶段只用于串口通信、H7同步和触手选择验证，不控制电机、不发送ACT_FRAME。

## 2. 串口参数

第一阶段：

```text
115200 bit/s
8 data bits
1 stop bit
no parity
no flow control
```

接入20 Hz完整ACT_FRAME前，PC和H7同时改为2,000,000 bit/s。

## 3. PC文本命令

每条命令以`\n`或`\r\n`结束。PC统一发送CRLF。

```text
ACT PING
ACT SELECT 1
ACT SELECT 2
ACT SELECT 3
ACT SELECT 4
ACT STATUS
```

命令编号：

```text
0 UNKNOWN
1 PING
2 SELECT
3 STATUS
```

H7当前命令行缓冲区为48字节。PC不得在一条命令中注入额外换行。

## 4. H7二进制回复

多字节字段均为little-endian：

| 偏移 | 类型 | 字段 | 说明 |
|---:|---|---|---|
| 0 | `uint16` | `magic` | 固定`0xA55A`，线上字节`5A A5` |
| 2 | `uint8` | `type` | 包类型 |
| 3 | `uint8` | `version` | 当前为1 |
| 4 | `uint16` | `data_length` | data字节数 |
| 6 | `uint8[N]` | `data` | payload |
| 6+N | `uint32` | `crc32` | 对头部和data计算，不含CRC本身 |

固定开销为10字节。当前包类型：

```text
1 ACK
2 STATUS
3 ERROR
```

解析器必须支持半包、粘包、无效前缀、CRC错误和重新寻找magic。PC最大允许data长度暂定8192字节，为后续约4.2KB的ACT_FRAME留出余量。

## 5. CRC32

CRC与Python `zlib.crc32()`一致：

```text
反射多项式：0xEDB88320
初值：0xFFFFFFFF
最终异或：0xFFFFFFFF
check("123456789") = 0xCBF43926
```

## 6. ACK和ERROR

ACK与ERROR的data均为2字节：

```text
data[0] command_id
data[1] result
```

结果编号：

```text
0 OK
1 BAD_COMMAND
2 BAD_ARGUMENT
```

`ACT STATUS`直接返回STATUS，不再返回ACK。

## 7. STATUS

当前data固定12字节：

| 类型 | 字段 |
|---|---|
| `uint8` | selected_tentacle |
| `uint8` | control_enabled |
| `uint8` | capture_state |
| `uint8` | reserved |
| `uint32` | sent_frame_count |
| `uint32` | dropped_frame_count |

后续可以在12字节之后追加ONLINE、READY和FAULT字段，但不能改变现有前12字节顺序。PC必须按data_length兼容解析。

## 8. 请求—应答规则

第一阶段没有通用命令sequence，因此PC同时最多只能等待一个状态请求：

```text
ACT PING -> PING ACK
ACT STATUS -> STATUS
ACT SELECT n -> SELECT ACK -> ACT STATUS -> STATUS
```

PC打开串口后，只有PING ACK和STATUS都合法才显示“H7已同步”。打开COM不等于协议同步。

PING超时允许重发一次。SELECT不自动重发，防止未来协议扩展后重复执行有副作用的命令。

## 9. 后续命令预留

第二阶段计划：

```text
ACT ENABLE 1
ACT ENABLE 0
ACT MOVE x y bend stiff
ACT HOME
ACT STOP
ACT REC 1
ACT REC 0
```

这些命令在H7实现前，PC界面必须保持对应控件禁用。

`ACT MOVE`最高20 Hz，只发送最新目标，不等待逐帧ACK。STOP保持最高优先级。

## 10. 后续数据包待冻结项

第二阶段需要定义实时姿态TELEMETRY，至少包含选中触手的状态和`actual_q[3]`。

第三阶段需要定义ACT_FRAME精确字段偏移。新需求采用10个CNH区间和未来12帧actual监督标签，但当前H7手势通道仍为8个CNH区间，必须先完成独立ACT采集模式，不能直接修改现有手势CNN通道宏。

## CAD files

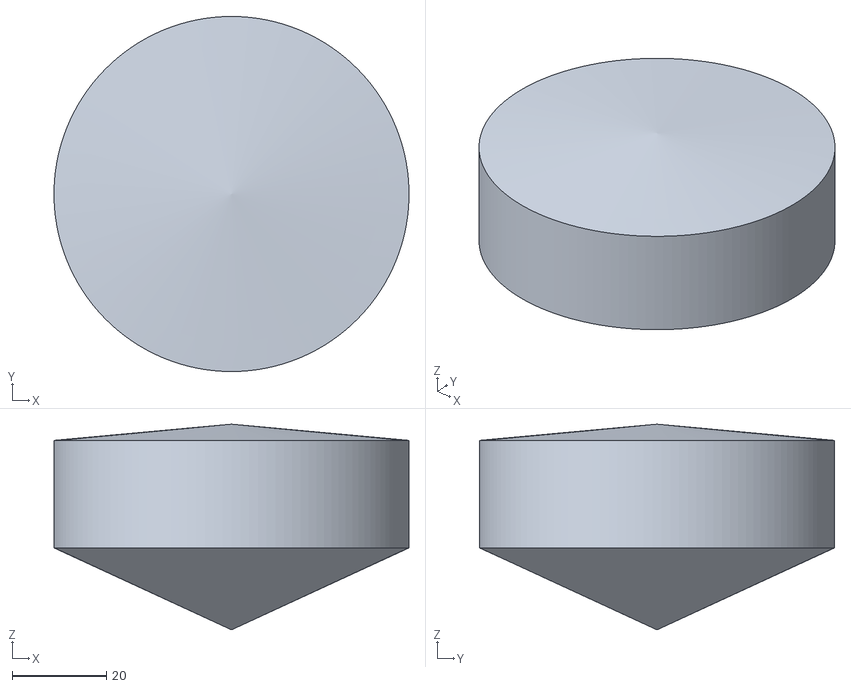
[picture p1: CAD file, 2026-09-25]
pc/tentacle-controller/assets/model/baselink.stl
75.3 x 75.3 x 43.6

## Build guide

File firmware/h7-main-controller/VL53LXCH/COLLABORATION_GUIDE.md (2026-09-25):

# 协作方式与项目推进习惯

本文档用于记录后续与 Codex 协作时的偏好、边界和推荐流程。开始新的任务前，应优先阅读本文档和当前项目上下文文档。

## 1. 总体工作习惯

当前更适合采用“先搭框架、再逐步验证”的推进方式。

不要一开始就追求完整功能闭环，而应优先完成可以独立验证的软件模块、调试链路和底层接口。对于硬件条件尚未完全具备的功能，应先完成接口、数据结构和可模拟验证的逻辑，等待硬件具备条件后再实测。

推荐推进顺序：

1. 明确当前阶段目标。
2. 搭建最小软件框架。
3. 加入可观测的调试输出。
4. 通过静态检查、编译或假数据验证。
5. 标记哪些内容已经验证，哪些仍需硬件实测。

## 2. 安全边界

涉及电机、PWM、DRV、功率板、电流采样、执行器输出等内容时，默认采用保守策略。

在没有明确要求或硬件条件未确认前，不应擅自：

- 启动真实 PWM 输出。
- 使能 DRV 或功率级。
- 修改可能导致电机直接动作的默认状态。
- 假定 ADC 电流采样比例、方向、零漂已经正确。
- 假定编码器方向、零点、多圈计数已经通过实物验证。

对于高风险功能，代码状态需要明确区分：

- `已静态实现`：代码已写好，但未上板验证。
- `已链路验证`：中断、DMA、通信、回调或数据流已经跑通。
- `已硬件实测`：真实硬件数据和行为已经确认。

## 3. 模块化偏好

代码应按功能层拆分，避免把底层驱动、应用调度、控制算法和调试输出混在一起。

推荐保持类似以下分层：

- 底层外设入口：HAL 回调、中断、DMA 完成回调。
- 应用层封装：定时任务、传感器读取、调试输出。
- 驱动模块：传感器、DRV、编码器、ADC 数据组织。
- 控制算法：PID、限幅、斜坡、死区、滤波、FOC 数学。
- 状态机：设备或电机的 INIT、CALIB、READY、RUN、FAULT 等状态。
- 调试接口：VOFA、串口输出、关键变量观测。

新增代码应优先沿用现有目录结构、命名风格和回调转发方式。

## 4. 调试与可观测性

调试输出是验证代码的重要组成部分。修改控制算法、传感器链路或底层数据流时，应同步考虑如何观察关键变量。

优先使用已有调试链路，例如：

- VOFA JustFloat 波形输出。
- 串口调试变量。
- raw buffer、状态标志、错误码。
- 关键中间量，例如角度、速度、sector、CCR、ADC raw、DMA 完成标志。

判断一个模块是否完成时，不只看代码是否写完，还要看是否有足够方式确认它正在按预期工作。

## 5. 中断与主循环原则

中断和 HAL 回调中应保持短小。

推荐原则：

- 中断中只置标志、记录轻量状态或做回调转发。
- 复杂计算放在主循环、低频任务或模块内部任务函数中。
- DMA 完成后尽量通过模块回调统一处理。
- 不在中断中加入耗时调试输出或复杂控制逻辑。

## 6. 任务开始前的协作流程

每次开始新的开发任务时，Codex 应优先执行：

1. 阅读当前项目上下文文档。
2. 查看相关源码和现有模块风格。
3. 明确本次任务会修改哪些文件。
4. 判断是否涉及硬件风险或实时链路风险。
5. 给出简短执行计划后再修改代码。

如果任务很小，可以直接执行；如果涉及 PWM、DRV、电机、电流采样或硬件动作，应先说明安全边界。

## 7. 修改后的交付要求

每次修改完成后，回复中应说明：

- 修改了哪些模块或文件。
- 本次实现到什么程度。
- 已经如何验证。
- 哪些内容仍未验证。
- 是否需要后续上板、接硬件或看 VOFA 波形确认。

对于 STM32 工程，优先尝试进行可行的编译或静态检查。如果当前环境无法编译，应明确说明未能编译验证。

## 8. 文档维护方式

建议当前工程长期保留以下文档：

- `PROJECT_CONTEXT.md`：当前工程目标、硬件资源、软件结构、当前状态。
- `WORKLOG.md`：每次修改记录、验证结果、遗留问题。
- `TODO.md`：短期任务列表和优先级。
- `COLLABORATION_GUIDE.md`：协作习惯和工作方式约定。

当完成较大的功能、修复关键问题或改变硬件资源规划时，应同步更新项目上下文或工作日志。

## 9. 推荐沟通方式

用户适合给出明确的阶段目标，例如：

- “先读上下文，然后继续做编码器 VOFA 输出。”
- “不要启动 PWM，只验证 CCR 写入。”
- “先搭控制算法模块，用假数据验证。”
- “这次只做静态框架，不接真实硬件。”

Codex 应按阶段推进，不擅自扩大范围，不把未验证内容描述为已完成。

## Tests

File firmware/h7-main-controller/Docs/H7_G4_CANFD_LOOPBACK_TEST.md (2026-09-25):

# H7-G4 CAN FD 串口触发闭环测试说明

## 1. 测试目标

本测试用于验证整条通信链路是否打通：

```text
电脑串口助手 / VOFA
  -> USART1
  -> H7
  -> CAN FD 0x120
  -> G4
  -> CAN FD 0x180
  -> H7
  -> USART1
  -> 电脑串口助手 / VOFA
```

该测试的目标不是验证触手运动算法，也不是验证最终模型推理，而是先确认：

1. H7 能通过 USART1 收到上位机命令。
2. H7 能发送 CAN FD + BRS 的 0x120 控制帧。
3. G4 能收到并解析 H7 的 0x120 帧。
4. G4 能发送 CAN FD + BRS 的 0x180 状态帧。
5. H7 能收到并解析 G4 的 0x180 帧。
6. H7 能把结果通过 USART1 打印给上位机。

## 2. CAN FD 物理层和 CubeMX 配置要求

H7 和 G4 必须保持一致：

```text
Frame Format: CAN FD with BRS
Nominal bitrate: 1 Mbit/s
Data bitrate:    5 Mbit/s
Data field size: 32 bytes
```

硬件要求：

```text
CAN FD 收发器支持 5M 数据段
总线两端 120R 终端电阻正确
H7 和 G4 共地
CANH/CANL 连接正确
线尽量短，先做桌面短线测试
```

## 3. H7 发给 G4 的命令帧

H7 发送：

```text
ID:      0x120
Format:  Standard ID
Frame:   CAN FD + BRS
DLC:     32 bytes
```

payload：

```text
byte0       protocol_version = 1
byte1       command
byte2       flags
byte3       motor_mask
byte4       seq
byte5..7    reserved
byte8..11   motor0_target_q int32 little-endian
byte12..15  motor1_target_q int32 little-endian
byte16..19  motor2_target_q int32 little-endian
byte20..31  reserved
```

命令定义：

```text
command = 0x01  position target
command = 0x02  stop
```

flags：

```text
bit0 ENABLE = 0x01
bit1 STOP   = 0x02
bit3 APPLY  = 0x08
```

第一版位置命令使用：

```text
command = 0x01
flags = 0x09
motor_mask = 0x07
```

停止命令使用：

```text
command = 0x02
flags = 0x02
motor_mask = 0x07
```

位置缩放：

```text
target_q = motor_target_rad * 100000
motor_target_rad = target_q / 100000.0f
```

示例：

```text
CANPOS 1000 0 0
```

表示：

```text
motor0 = 0.01 rad
motor1 = 0
motor2 = 0
```

## 4. G4 需要做什么

G4 侧至少需要实现以下逻辑。

### 4.1 接收 0x120

G4 应配置 FDCAN 接收标准 ID：

```text
0x120
```

收到帧后检查：

```text
ID == 0x120
DLC == 32 bytes
FD == enable
BRS == enable
byte0 protocol_version == 1
```

若检查通过，解析：

```text
command
flags
motor_mask
seq
motor0_target_q
motor1_target_q
motor2_target_q
```

### 4.2 更新接收统计

G4 收到有效 0x120 后应更新：

```text
rx_count++
last_position_seq = seq
last_position_flags = flags
last_position_motor_mask = motor_mask
last_position_command = command
```

如果帧格式错误，可以更新：

```text
error_count++
```

### 4.3 执行策略

闭环测试第一阶段建议不要直接大幅运动。

推荐策略：

1. `command = 0x02 STOP` 时进入停止或保持状态。
2. `command = 0x01 POSITION` 且 `flags & 0x09 == 0x09` 时接受目标。
3. 初期可以只更新 pending/last target，不立即启动电机。
4. 确认通信稳定后，再允许小幅位置执行。

## 5. G4 返回给 H7 的状态帧

G4 发送：

```text
ID:      0x180
Format:  Standard ID
Frame:   CAN FD + BRS
DLC:     32 bytes
```

payload：

```text
byte0      protocol_version
byte1      board_id
byte2      online
byte3      control_word
byte4..5   rx_count low16 little-endian
byte6..7   tx_count low16 little-endian
byte8..11  error_count uint32 little-endian
byte12     pwm_started_mask
byte13     last_relative_seq
byte14     last_relative_seq_valid
byte15     position_pending
byte16     last_position_seq
byte17     last_position_flags
byte18     last_position_motor_mask
byte19     last_position_command
byte20..31 reserved
```

建议 G4 周期发送 0x180：

```text
10Hz ~ 100Hz 均可
第一版建议 20Hz 或 50Hz
```

如果 G4 暂时还没有周期状态任务，也可以在每次收到 0x120 后立即回一帧 0x180。

## 6. H7 串口测试命令

H7 通过 USART1 接收文本命令。

建议使用 VOFA 或串口助手发送 `Abc` 字符串，并带 `\r\n`：

```text
CANSTAT\r\n
CANSTOP\r\n
CANPOS 0 0 0\r\n
CANPOS 1000 0 0\r\n
```

### 6.1 CANSTAT

查询 H7 当前 CAN 状态和最近一次 G4 状态。

预期返回示例：

```text
CAN ready=1 tx=0 g4_valid=1 online=1 age=12 rx=25 g4rx=3 g4tx=25 err=0 last_seq=2 cmd=1 flags=9 mask=7 pending=0 pwm=7
```

关键字段：

```text
ready=1      H7 FDCAN app 初始化成功
g4_valid=1   H7 已经收到过 G4 0x180
online=1     G4 声明在线
age          距离最近一次收到 0x180 的时间
rx           H7 收到 0x180 的次数
g4rx         G4 收到 0x120 的计数 low16
err          G4 错误计数
last_seq     G4 最近收到的位置命令 seq
cmd          G4 最近收到的位置命令 command
flags        G4 最近收到的位置命令 flags
mask         G4 最近收到的位置命令 motor_mask
```

### 6.2 CANSTOP

H7 发送 stop 帧。

预期返回：

```text
OK CANSTOP status=0 tx=1
```

若失败：

```text
ERR CANSTOP status=x
```

### 6.3 CANPOS

H7 发送三电机目标位置定点值。

示例：

```text
CANPOS 0 0 0
CANPOS 1000 0 0
```

预期返回：

```text
OK CANPOS 1000 0 0 status=0 tx=2
```

若失败：

```text
ERR CANPOS status=x
```

## 7. 推荐测试顺序

### 7.1 只看 G4 状态

先不要发位置命令，只让 G4 周期发 0x180。

H7 串口发送：

```text
CANSTAT
```

期望：

```text
ready=1
g4_valid=1
online=1
rx 持续增加
```

### 7.2 发 STOP

H7 串口发送：

```text
CANSTOP
```

然后发送：

```text
CANSTAT
```

期望 G4 的 `g4rx` 增加。

### 7.3 发零目标

H7 串口发送：

```text
CANPOS 0 0 0
```

然后发送：

```text
CANSTAT
```

期望：

```text
last_position_command = 1
last_position_flags = 9
last_position_motor_mask = 7
error_count 不增加
```

### 7.4 发小目标

确认电机安全后，发送很小目标：

```text
CANPOS 1000 0 0
```

含义是 motor0 目标约 `0.01 rad`。

第一版不要直接发送大目标。

## 8. 闭环通过标准

满足以下条件即可认为通信闭环打通：

```text
H7 CANSTAT 显示 ready=1
H7 CANSTAT 显示 g4_valid=1
H7 能看到 G4 0x180 rx 计数增加
H7 发送 CANSTOP 后 G4 rx_count 增加
H7 发送 CANPOS 后 G4 last_position_seq / cmd / flags / mask 更新
G4 error_count 不持续增加
```

## 9. 常见问题

### 9.1 H7 ready=0

说明 H7 的 `Can_App_Init()` 未成功。

检查：

```text
FDCAN CubeMX 配置
FDCAN 时钟
Message RAM
是否调用 Can_App_Init()
```

### 9.2 g4_valid=0

说明 H7 没有收到 G4 的 0x180。

检查：

```text
G4 是否发送 0x180
H7/G4 波特率是否一致
CAN FD/BRS 是否一致
收发器是否支持 CAN FD 5M
终端电阻和接线
```

### 9.3 G4 收不到 0x120

检查：

```text
H7 是否执行 CANPOS/CANSTOP
H7 tx 是否增加
G4 filter 是否接收 0x120
G4 Message RAM element size 是否为 32 bytes
G4 是否打开 FDCAN Start 和 RX 中断
```

### 9.4 error_count 持续增加

优先检查：

```text
Nominal 1M / Data 5M 是否一致
BRS 是否一致
GPIO speed
CAN FD 收发器能力
总线终端电阻
H7/G4 是否共地
```

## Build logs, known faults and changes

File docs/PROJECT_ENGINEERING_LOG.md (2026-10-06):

# 基于示教学习的多触手智能柔性末端执行器工程开发日志

本文档用于记录本项目从 CubeMX 初始化、STM32G474 三电机 FOC 硬件联调，到 STM32H743 多触手控制、VL53L8CH 感知、示教数据采集、端侧模型训练部署和整机验证过程中遇到的主要问题、解决方式及仍需继续处理的事项。

记录原则：

- 优先记录工程事实，不写空泛总结。
- 每个问题尽量包含：现象、原因判断、处理方法、当前状态。
- 后续可以根据 Git commit 和工程快照补充具体日期。
- 本文档偏工程记录，不是正式论文或汇报稿。

---

## 1. 项目基本信息

### 1.1 项目目标

使用 STM32G474VET6 控制 3 个 BM352006 无刷电机，用于带减速器和线轮的拉索式机构。

当前软件目标是：

- 先完成单电机 FOC 链路。
- 再验证电流环、速度环、位置环。
- 最后扩展到三电机统一管理和调度。

### 1.2 当前硬件分工

| 功能 | 外设 | 说明 |
|---|---|---|
| 电机 1 PWM | TIM1 | 三相互补 PWM |
| 电机 2 PWM | TIM8 | 三相互补 PWM |
| 电机 3 PWM | TIM20 | 三相互补 PWM，当前主要调试对象 |
| 电流采样 | ADC1 / ADC3 / ADC4 | 每个 ADC 采一个电机三相电流 |
| 温度/辅助采样 | ADC2 | 低频模拟量采样 |
| DRV 配置 | SPI1 | 配置 DRV8323S/DRV8328 |
| 编码器读取 | SPI3 | 读取 SPI 磁编码器 |
| 调试串口 | USART1 | VOFA JustFloat |
| 主控通信 | FDCAN1 | 后续与上位主控通信 |

### 1.3 当前重点调试链路

当前主要以一台电机为对象进行联调：

```text
TIM20 PWM
-> DRV3
-> 电机
-> ADC1 三相电流采样
-> SPI3 编码器 CSN3
-> motor_core 电流环/FOC
-> VOFA 观察
```

---

## 2. 软件模块结构

| 模块 | 主要作用 |
|---|---|
| `Config.h` | 全局参数、限幅、默认 PID、采样配置 |
| `Motor_type.h` | 电机对象、控制状态、采样数据结构 |
| `control_pid.c/h` | 通用 PID 基础算法 |
| `foc_drive.c/h` | Clarke/Park/SVPWM/CCR 写入 |
| `motor_core.c/h` | 单电机控制主链路、校准、闭环接口 |
| `adc_app.c/h` | ADC DMA 启动、稳定帧缓存、诊断 |
| `spi_encoder.c/h` | SPI 编码器 DMA 读取、角度、多圈、速度 |
| `drv_drive.c/h` | DRV8323S 寄存器读写、默认配置、CAL 控制 |
| `Vofa_debug.c/h` | VOFA JustFloat 调试主题 |
| `timer_app.c/h` | 定时任务、TIM4/TIM6/TIM7/TIM3 等辅助节拍 |

目前文件划分的基本原则：

```text
Config.h       只放参数
Motor_type.h   只放数据结构
control_pid    只做通用 PID
foc_drive      只做 FOC 数学和 PWM 写入
motor_core     组织单电机控制数据流
```

---

## 3. 已完成的重要工作

### 3.1 VOFA 调试链路

完成内容：

- 使用 USART1 输出 VOFA JustFloat 数据。
- 支持多调试主题切换。
- 使用 DMA 发送，避免阻塞主循环。
- 已经用于观察 ADC、编码器、DRV、FOC、电流环、速度环等数据。

遇到的问题：

- 一开始串口没有数据。
- VOFA 收到字节但不显示波形。
- 通道含义不明确，容易误判。
- 发送频率太高会影响系统观测和主循环响应。

解决方式：

- 确认 USART1 初始化、DMA、中断回调链路。
- 使用 JustFloat 正确帧尾。
- 给每个主题固定通道含义。
- 根据调试目标调整 VOFA 周期。

当前状态：

- VOFA 可正常使用。
- KEY3 可切换调试主题。
- 后续仍需要控制通道数量，避免高频调试影响实时性。

---

### 3.2 Git 与工程快照

完成内容：

- 在工程目录初始化 Git。
- 添加 `.gitignore` 过滤编译产物。
- 形成关键节点 commit 的习惯。
- 重要阶段额外做工程快照。

遇到的问题：

- 一开始不熟悉 `git status`、`git add`、`git commit`、`git show`。
- Git Bash 偶尔卡死。
- CubeMX 重新生成后担心覆盖用户代码。

解决方式：

- 用 Git 记录每个稳定节点。
- 大改前先 commit 或快照。
- CubeMX 生成后用 diff 检查被改动文件。

当前状态：

- Git 已经成为工程回退和记录工具。
- 后续可以根据 Git log 反推调试时间线。

---

### 3.3 ADC 采样链路

完成内容：

- 建立 `adc_app` 模块。
- ADC1/ADC3/ADC4 分别采三相电流。
- 使用 DMA 和软件稳定帧缓存。
- 增加 ADC 诊断主题。
- 增加 STM32 ADC 自校准接口。

遇到的问题：

- ADC raw 不更新或固定。
- DMA 完成计数很慢或异常。
- Continuous mode 和外部触发逻辑混乱。
- VOFA 读取与控制链路消费数据互相影响。
- TIM20 触发 ADC 的位置会影响采样真实性。
- 低侧采样窗口不足时，某些相电流会失真。

解决方式：

- 关闭不合适的连续转换模式。
- 使用 TIM 触发 ADC。
- DMA 完成后只更新稳定帧和标志。
- 控制链路逐步转到 ADC 完成后执行。
- 尝试使用 TIM20 CC3 / TRGO2 作为采样触发点。
- 引入 duty 限幅和三相电流重构思路。

当前状态：

- ADC 链路能够运行。
- 电流环可以基于 ADC 数据闭环。
- 低侧采样窗口和负载下采样畸变仍是重要风险。

待继续处理：

- 验证不同 duty 下 raw 是否贴近 2048 或削顶。
- 验证 `ia + ib + ic` 是否接近 0。
- 验证堵转/负载下三相采样是否真实。
- 后续可能需要更完善的低侧采样重构策略。

---

### 3.4 DRV8323S 配置

完成内容：

- 建立 DRV SPI 寄存器读写接口。
- 支持三路 DRV 片选互斥。
- 支持默认寄存器配置。
- 支持 CAL 引脚控制。
- 增加 DRV 检查 VOFA 主题。

关键配置：

```text
PWM_MODE = 6x PWM
VREF_DIV = VREF/2
CSA_GAIN = 20V/V
CSA_FET = 0，使用外部采样电阻
OCP / VDS 阈值按调试阶段配置
```

遇到的问题：

- 初期 SPI 读回异常。
- DRV 和电机编号对应关系混乱。
- 某些相报 VDS/OCP 故障。
- CSA 寄存器含义需要查手册确认。

解决方式：

- 对照 DRV8323S 手册修正 SPI 配置。
- 用 VOFA 读回寄存器确认写入值。
- 逐相启动 PWM 定位故障。
- 明确当前硬件使用外部低侧采样电阻，因此 `CSA_FET = 0`。

当前状态：

- DRV 寄存器读写正常。
- 6x PWM 配置正确。
- 当前可驱动电机转动。

待继续处理：

- 栅极驱动电流需要结合 MOSFET 和波形优化。
- MCU 死区和 DRV 内部死区需要继续验证。
- 保护阈值不能长期只靠放宽，需要最终定标。

---

### 3.5 SPI 编码器与电角度

完成内容：

- 建立 SPI 编码器读取模块。
- 从阻塞读取逐步改成 DMA 读取。
- 实现角度缓存、多圈计数、速度计算。
- 增加编码器 VOFA 主题。
- 电角度接入 FOC 控制。

遇到的问题：

- 编码器 CSN 对应关系多次变化。
- 转动时出现 valid 抖动和错误码。
- SPI 速度和抗干扰之间需要平衡。
- 电角度 offset 的定义和使用容易混淆。

解决方式：

- 明确每个电机对应的编码器 ID。
- 降低 SPI 速度进行验证。
- 在 DMA 回调中更新必要的角度缓存。
- 统一电角度公式：

```text
theta_elec = pole_pairs * theta_mech + foc_elec_offset
```

当前状态：

- 编码器角度可以用于 FOC。
- 仍需关注电机运行时 SPI 抗干扰和 valid 抖动。

待继续处理：

- 验证高速转动时角度是否连续。
- 验证堵转和负载扰动下角度是否稳定。
- 检查编码器线缆、地线、屏蔽和 SPI 速度。

---

### 3.6 FOC 输出链路

完成内容：

- 实现 Clarke 变换。
- 实现 Park / 反 Park。
- 实现归一化电压输入。
- 实现 SVPWM。
- 实现 duty 到 CCR 写入。
- 支持输出 50% 中性 PWM。

遇到的问题：

- Clarke/Park 推导需要反复确认。
- SVPWM 扇区判断、T1/T2/T0、duty 映射容易出错。
- CCR 与 duty 的关系一开始不直观。
- 停止 PWM 会导致 ADC 触发停止。

解决方式：

- 用 VOFA 观察 sector、T1/T2/T0、CCR。
- 停止时改为输出中性 50% PWM，避免直接关闭采样链路。
- 当前 TIM20 直接写 CCR，用于减少快环开销。

当前状态：

- 开环转动已经实现。
- FOC 数学链路基本可用。

待继续处理：

- 带负载时仍有卡顿感。
- 需要继续确认相序、电角度 offset、电流方向和死区误差。

---

### 3.7 FOC 电角度 offset 校准

完成内容：

- 实现单点 d 轴吸附校准。
- 校准时输出 `vd > 0, vq = 0, theta_cmd = 0`。
- 转子吸附后读取编码器机械角。
- 计算 `foc_elec_offset`。

校准核心逻辑：

```text
控制器人为定义 theta_cmd = 0 为 d 轴方向
给定 vd > 0 后，转子磁链被吸附到该方向
读取此时编码器机械角 theta_mech_align
计算 offset，使该位置在控制坐标中等于 0
```

遇到的问题：

- 一开始对“控制坐标 theta=0”和“编码器原始角度 0”关系理解不清。
- 两点校准流程容易受编码器错误和吸附不稳定影响。
- 校准有时会卡卡的。

解决方式：

- 暂时关闭两点校准。
- 回退到单点锁定校准。
- 保留两点校准代码，后续有需要再恢复。

当前状态：

- 单点校准可用。
- offset 精度仍可能影响负载下扭矩平滑性。

待继续处理：

- 验证校准后 `id` 是否接近 0。
- 验证给 `iq` 后是否明显混入 `id`。
- 后续可尝试双向吸附平均或更稳的两点校验。

---

### 3.8 电流环控制

完成内容：

- 实现 id/iq 电流环 PID。
- 电流环输出 vd/vq。
- vd/vq 经 FOC 输出到 PWM。
- 电流环已经能够让电机运行。

遇到的问题：

- iq/id 波形抖动。
- 堵转时 iq 可能飙高。
- 电机负载下有类似步进吸附的卡顿。
- 三相电流在某些状态下被削顶。
- 快环放进 ADC 回调后电机更稳，但 VOFA 和按键变卡。

解决方式：

- 将电流环放到 ADC DMA 完成后运行。
- 对快环做减负：缓存 ARR、直接写 CCR、减少通用函数调用。
- 调整 duty 限幅和采样点。
- 尝试三相电流重构。
- 排查空载 `id` 规律震荡时，曾重点怀疑电角度 offset、重构相切换和 ADC 采样点。
- 最终确认主要原因之一是电流环死区设置过大：小误差被死区吞掉，误差积累后再突然参与控制，形成规律震荡。
- 缩小电流环死区后，空载电流环稳定性明显改善，电机运行恢复平顺。

当前状态：

- 电流环可以跑。
- 空载和带负载表现均已有明显改善。
- 当前新电机电流环已基本稳定，可作为后续速度环和位置环调试基础。

待继续处理：

- 确认电流采样真实性。
- 确认 iq/id 方向和相序。
- 在当前较小死区基础上继续细调 PID 参数。
- 后续调参时必须记录死区数值，避免再次把过大死区误判为电角度或采样问题。

---

### 3.8.1 空载 id 规律震荡问题记录

现象：

- 新换电机后，电流环空载运行时 `id` 出现规律性震荡。
- 有负载或用手按住电机时反而更稳定。
- `CH2/CH3` 即 `i_alpha/i_beta` 在有有效电流时能呈现正弦/余弦关系。
- 一度怀疑电角度 offset、重构相切换、采样窗口和反电动势补偿。

检查过程：

- 固定重构相后，`id` 震荡减轻，但按住电机时出现尖叫和卡顿，说明固定重构相只能用于定位，不能作为正常运行方案。
- 尝试观察 `id/iq`、`i_alpha/i_beta`、三相电流、重构相编号和 ADC 触发 CCR。
- 发现有负载时电机和电流表现反而正常，说明电角度大错误的可能性下降。
- 继续检查电流环参数后确认，过大的电流环死区会让小电流区反馈迟钝，导致误差周期性积累和释放。

最终原因：

- 主要原因是电流环死区设置过大。
- 空载时真实电流较小，死区占比过大，电流环不能连续细微调节。
- 误差越过死区后控制量突然变化，表现为规律性 `id` 震荡和空载不平顺。

处理结果：

- 调小电流环死区后，电机空载稳定性明显改善。
- 当前电流环已达到比较稳定的状态。
- 后续速度环、位置环调试应基于当前较小死区配置，不要再随意放大死区。

经验记录：

- `id` 规律震荡不一定优先等同于电角度错误。
- 如果“有负载正常、空载震荡”，应优先检查低电流区死区、零漂和测量信噪比。
- 死区属于控制非线性，过大时会制造类似步进/吸附/周期震荡的现象。

---

### 3.9 速度环和位置环

完成内容：

- 建立 PID 基础模块。
- 建立单电流环、单速度环、单位置环接口。
- 建立速度-电流双环接口。
- 建立位置-速度双环和三环接口。
- TIM7 当前用于速度计算和速度外环。

遇到的问题：

- 电流环、速度环、位置环频率不同。
- 速度环接入后，KEY2 行为从单电流环变成速度电流双环，调试时容易混淆。
- 速度环依赖电流环稳定，否则无法判断速度环本身是否有问题。

解决方式：

- 通过 mode 区分控制模式。
- 外环只更新目标，内环在 ADC 回调中执行。
- 测试时先低速、低电流、短时间。

当前状态：

- 速度环软件结构已具备。
- 实机调参尚未完成。

待继续处理：

- 先稳定电流环，再正式调速度环。
- 速度环方向、限幅、PID 参数需要逐步验证。
- 位置环暂不急于实机闭环。

---

### 3.10 2026-05-31 长周期联调问题汇总

本节记录本轮长对话中连续排查的问题链路。记录重点是“现象 -> 判断 -> 修改/验证 -> 结果”，用于后续断电、换电机或回退版本时快速恢复上下文。

#### 3.10.1 CAN / FDCAN 通信方案讨论

现象和需求：

- 当前电流采样问题一度阻塞速度环和电流环继续推进。
- 后续需要开始规划与 H7 主控之间的 CAN 通信。
- 讨论过标准 CAN、扩展 CAN ID、CAN FD / FDCAN 的区别，以及是否需要单独 `can_app`。

处理结论：

- 标准 CAN 更适合简单、兼容性强、数据量小的控制命令和状态反馈。
- CAN FD / FDCAN 更适合后续较大数据包、高速调试、更多状态量和扩展协议。
- 工程结构上建议后续单独建立 `can_app`，不要把通信解析散落在 `main.c` 或 motor 模块内。

当前状态：

- 当前阶段仍以单电机 FOC 联调为主，FDCAN 仅完成方案讨论，尚未作为主线实现。
- 后续进入主控通信阶段时，应先定义帧 ID、数据缩放、心跳、故障码和电机编号映射。

#### 3.10.2 MT6816 SPI 编码器读取问题

现象：

- MT6816 通过 SPI3 + DMA 读取角度时，静止大多正常，手动转动或电机转动时频繁出现 parity / no magnet / frame 错误。
- 曾怀疑 SPI 速度、软件分频、CS 时序、DMA 回调被打断、不完整帧等问题。
- 一度出现角度通道从小值直接跳到大值，导致电机震动。

检查和修改：

- 对照 MT6816 手册重新确认 8-bit SPI 读取方式。
- 尝试过 3 字节连续读取、4 字节读取、分两次读取高低寄存器等方式。
- 优化 CS 释放位置，确认 DMA 完成回调后才释放 CS。
- 尝试 SPI 分频、TIM7 读取频率、软件二分频和单回调读取。
- 增加 VOFA 原始接收缓存观测，定位原始字节跳变。

结果：

- 最终确认其中一部分异常来自编码器芯片本身，换芯片后角度读取明显恢复正常。
- 编码器读取链路目前可支持后续闭环调试。
- 经验上，编码器问题不能只看校验错误率，也要直接观察原始 RX 字节和 angle jump。

#### 3.10.3 编码器测速与速度环输入

现象：

- 速度环接入后，实际速度曲线震荡尖锐，P 项很小仍然会出现规律波动。
- 简单单次差分、滑动窗口、固定 dt、DWT 时间差等方案都讨论过。
- 曾出现堵转后松开产生速度尖峰，速度环输出 `iq_ref` 呈波浪状。

检查和修改：

- 讨论过编码器 4 kHz 更新、TIM7 1 kHz 速度环之间的关系。
- 尝试从“每次 TIM7 用上一次角度差分”简化，再恢复滑动窗口思路。
- 明确速度环不需要 16 kHz 角度刷新，但电流环 FOC 电角度需要尽量新。
- 快环中加入编码器快照和时间戳预测，降低 FOC 电角度滞后。

结果：

- 电角度预测补偿量实测较小，对主要问题改善有限。
- 速度环震荡的根因不能单独归因于测速算法，后续发现电流环死区过大才是空载规律震荡的重要原因。
- 速度环和位置环必须建立在稳定电流环基础上继续整定。

#### 3.10.4 低侧电流采样、三相重构和 ADC 触发点

现象：

- 早期相电流波形出现削顶，且削顶位置接近 ADC 中点 2048。
- 按 duty 判断有效窗口并重构后，波形改善，但动态重构相切换时 `id` 曾出现规律震荡。
- 关闭重构后电流环更差，说明低侧采样窗口确实需要重构或采样点约束。

检查和修改：

- 修改过 ADC 触发 CCR 计算，使采样点避开 PWM 边沿、死区和振铃区。
- 增加 VOFA 对 raw / 重构后电流 / 重构相 / ADC 触发 CCR 的观察。
- 尝试固定重构相，发现固定后 `id` 可明显变稳，但负载下会尖叫、卡顿，说明固定重构相只能定位问题，不能作为正常运行方案。
- 尝试过重构相滞回和最小保持周期。

结果：

- 动态重构相/采样点确实会影响低电流区 `id` 波动。
- 但最终空载规律震荡的主因不是重构切换本身，而是电流环死区过大。
- 后续仍需保留对采样窗口、重构相和 ADC CCR 的 VOFA 观测能力。

#### 3.10.5 新 4010 电机参数与相序/方向验证

现象：

- 更换新电机后，根据电机参数重新评估电流环参数。
- 新电机为 24N22P、极对数 11、相电阻约 8.6 欧、线绕参数 40、12-24V、最大瞬时电流约 2A。
- 校正时观察到电机从 0 到 2pi 方向和预期相反。

检查和修改：

- 更新了极对数等相关配置用于验证新电机。
- 讨论过电机 UVW 未标识时如何确认相序：先保证软件 PWM 相、ADC 采样相和实际驱动相一一对应，再通过小电流开环/闭环验证方向。
- 明确电机三相线本身可以互换，但软件中的 PWM 相序、ADC 相序、编码器方向和 FOC 电角度必须整体一致。

结果：

- 当前新电机能够进入稳定电流环状态。
- 相序和编码器方向后续仍应在速度环、位置环接入后继续低风险验证。

#### 3.10.6 电角度 offset 校正问题

现象：

- 不校正时，三相电流和 `i_alpha/i_beta` 在有有效电流时反而更接近正弦。
- 一旦进行电角度 offset 校正，`id` 曾出现规律震荡，波形变差。
- 这导致一度怀疑校正公式、编码器方向、d 轴吸附是否存在 180 度歧义。

检查和修改：

- 将两点校正暂时关闭，回到单点 d 轴吸附。
- 把 offset 计算公式抽成可切换形式：

```text
offset = wrap(ALIGN_ELEC + MECH_SIGN * mech_angle * pole_pairs)
```

- 用 `MOTOR_FOC_OFFSET_ALIGN_ELEC_RAD` 和 `MOTOR_FOC_OFFSET_MECH_SIGN` 验证吸附角定义和机械角符号。

结果：

- 校正链路仍需保留，因为上电初始机械角随机，不能依赖“刚好不校正能跑”。
- 但本轮最终确认，空载规律震荡的主要矛盾不是 offset 本身，而是电流环死区过大。
- 后续校正逻辑应继续使用单点吸附先验证，避免两点 ramp 过程引入额外变量。

#### 3.10.7 电流环死区过大导致空载规律震荡

现象：

- 空载时 `id` 规律震荡，电机有类似步进或吸附感。
- 有负载或手按电机时反而稳定。
- 单独看 `vq/vd` 有时并不剧烈，但 `id` 会呈周期性包络。

最终原因：

- 电流环死区设置过大。
- 空载小电流时，真实反馈和误差都很小，过大死区会让控制器长时间不动作。
- 误差积累到越过死区后，控制量突然介入，形成周期性震荡。

处理结果：

- 调小电流环死区后，电机空载和负载稳定性明显改善。
- 当前电流环基本稳定，这是本轮联调最重要的收敛点。
- 后续整定速度环和位置环前，必须记录并保持当前有效死区，不要再次把死区放大。

#### 3.10.8 速度环和位置环当前结论

现象：

- 速度环曾出现啸叫、卡顿、`iq_ref` 周期波动。
- 位置环已经能初步工作，但受速度环和电流环稳定性影响明显。

处理结论：

- 速度环输出只应作为 `iq_ref`，位置环输出只应作为 `speed_ref`。
- 外环需要在电流环稳定后重新整定，不能在电流环死区过大时判断外环参数好坏。
- 当前应以“稳定电流环 -> 低增益速度环 -> 位置环”的顺序继续。

当前状态：

- 位置环基础链路已基本完成。
- 当前重点应转为在稳定电流环基础上重新整定速度环，降低啸叫和规律速度波动。

---

### 3.11 2026-06-03 速度环、位置锁定和三线机构控制思路补充

本节记录在电流环基本稳定后，继续调试速度环、位置环和软体机器人三线控制方式时形成的结论。记录重点仍按“三要素”整理：现象、原因判断、修改/处理结果，并额外列出注意事项。

#### 3.11.1 KEY2 速度环阶跃测试序列

现象：

- 需要单独观察速度环从一个目标速度切换到另一个目标速度时的跟踪速度、超调和 `iq_ref` 输出变化。
- 原 KEY2 逻辑第一次按进入速度环目标 `20 rad/s`，第二次按直接停止，不方便观察 `20 -> 35 -> 20` 这种速度阶跃过程。

原因判断：

- 速度环问题不能只看单一目标速度。
- 需要在不改控制算法的前提下，用按键生成可重复的目标速度阶跃序列，方便 VOFA 对比目标速度、实际速度、速度误差、`iq_ref` 和速度 PID 各项输出。

修改/处理结果：

- 在 `main.c` 中增加 KEY2 速度测试步进状态。
- 当前 KEY2 循环为：

```text
第一次按：速度环目标 20 rad/s
第二次按：速度环目标 35 rad/s
第三次按：速度环目标 20 rad/s
第四次按：停止并关闭 PWM
再次按下：重新从 20 rad/s 开始
```

- 该修改只改变测试入口，不改变速度环、电流环和 FOC 算法。

注意事项：

- KEY2 当前仍是调试入口，不能作为最终业务状态机。
- 速度阶跃测试时应先低电流、短时间、低负载验证，避免参数不稳时长时间啸叫或过流。
- 若后续 KEY2 改为三电机选择/位置帧测试，应先记录当前测试序列，避免丢失可复现实验条件。

#### 3.11.2 速度环 P 项目标附近震荡

现象：

- 速度环只给较小 P 项时，实际速度仍会在目标速度附近来回震荡。
- 观察到速度 PID 中 I 项较稳定，而 P 项随速度误差正负切换来回跳动。
- P 项太小会导致速度跟踪慢，P 项稍大又会在目标附近因为小误差和速度噪声产生反向输出，造成 `iq_ref` 周期波动。

原因判断：

- 固定 `Kp` 同时承担“远离目标时快速跟踪”和“接近目标时平稳保持”两个任务，矛盾较大。
- 远离目标时需要较大 P 项提供快速加减速；接近目标时需要降低 P 项敏感度，避免速度误差小幅波动直接变成转矩指令。
- 速度环硬死区不能很好解决这个问题，因为通用 PID 死区会直接把误差置零，可能让目标附近控制变软。

修改/处理结果：

- 在 `Config.h` 中增加速度环 P 项误差相关缩放参数：

```text
SPEED_PID_KP_MIN_SCALE
SPEED_PID_KP_FULL_ERROR_RAD_S
```

- 在 `Motor_Core_UpdateSpeedPid()` 中根据速度误差临时缩放速度环 `kp`：

```text
误差 >= SPEED_PID_KP_FULL_ERROR_RAD_S：使用完整 Kp
误差 <  SPEED_PID_KP_FULL_ERROR_RAD_S：按线性比例降到最小 Kp 比例
```

- PID 计算前临时修改 `motor->control.speed_pid.param.kp`，计算后恢复原值，避免永久污染 PID 参数。

注意事项：

- 该方法不是改变速度环目标，而是改变 P 项在不同误差区间的敏感度。
- `SPEED_PID_KP_MIN_SCALE` 太小会导致目标附近锁定发软；太大则目标附近仍可能震荡。
- `SPEED_PID_KP_FULL_ERROR_RAD_S` 太小会过早使用完整 P，目标附近抖动可能恢复；太大则远离目标时也被削弱，跟踪变慢。
- 速度环死区当前仍要重点关注：如果 `SPEED_DEADBAND_RAD_S` 仍较大，通用 PID 会把小速度误差置零，但已有积分仍参与输出，可能导致目标附近漂移。

#### 3.11.3 速度环积分分离和泄放

现象：

- 速度环跟踪慢时，容易怀疑需要加大积分。
- 但加大积分后，速度阶跃、堵转释放或位置锁定附近可能出现积分残留，导致过冲或慢慢漂过目标。
- 大速度误差阶段如果积分持续累加，等速度接近目标时积分可能还在原方向推动。

原因判断：

- 速度环积分主要用于消除稳态误差、补偿负载和摩擦，不适合在大误差加速/刹车阶段快速堆积。
- 大误差阶段主要应由 P 项和电流限幅决定响应；积分应冻结或缓慢泄放。
- 小误差阶段仍需要积分，否则带负载位置保持会发软。

修改/处理结果：

- 在 `Config.h` 中增加：

```text
SPEED_PID_INTEGRAL_ENABLE_ERROR_RAD_S
SPEED_PID_INTEGRAL_LEAK_FACTOR
```

- 在 `Motor_Core_UpdateSpeedPid()` 中，当速度误差大于阈值时：

```text
速度积分 *= SPEED_PID_INTEGRAL_LEAK_FACTOR
本次 PID 临时关闭积分
PID 计算后恢复原积分使能配置
```

- 这样大误差阶段不会继续积累速度积分，小误差阶段仍允许正常积分。

注意事项：

- 不能简单把速度环积分永久关闭，否则位置锁定和负载保持能力会下降。
- 泄放系数越小，积分退得越快，但负载保持力也更容易被削弱。
- 阈值越小，积分只在非常接近目标时工作；阈值越大，积分更容易参与跟踪，但过冲风险更高。
- 速度积分的符号和位置误差方向必须结合观察，不能只看速度误差。

#### 3.11.4 位置环从“死区清零”改为“锁定区”

现象：

- 原位置环到达死区后会清位置 PID、清速度 PID，并把 `speed_ref`、`iq_ref` 清零。
- 这样到位后不是伺服锁死，而是接近“松手”。
- 带负载或外力推动时，只有误差跑出死区后才重新输出，表现为保持不硬、边缘晃动或不能可靠锁住。

原因判断：

- 对伺服位置控制而言，到位附近不应是“不控制区”，而应是“小范围保持区”。
- 位置死区把误差直接吃掉，会降低保持刚度。
- 直接清 `iq_ref` 或清速度环积分会导致带负载时突然泄力，后续用于拉索机构存在安全风险。

修改/处理结果：

- 在 `Config.h` 中增加位置锁定区参数：

```text
POS_LOCK_ENTER_RAD
POS_LOCK_EXIT_RAD
POS_LOCK_KP_DEFAULT
POS_LOCK_KD_DEFAULT
POS_LOCK_SPEED_LIM_RAD_S
```

- 在 `motor_core.c` 中增加 `s_position_lock_active[MOTOR_COUNT]`，用进入阈值和退出阈值形成滞回。
- 锁定区内不清 `speed_pid`、不清 `iq_ref`，而是用小范围位置刚度和速度阻尼输出速度目标：

```text
speed_ref = POS_LOCK_KP_DEFAULT * pos_error
          - POS_LOCK_KD_DEFAULT * actual_speed
```

- 锁定区外仍使用普通位置 P + 速度阻尼：

```text
speed_ref = POS_PID_KP_DEFAULT * pos_error
          - POS_VEL_DAMPING_GAIN_DEFAULT * actual_speed
```

注意事项：

- `POS_LOCK_ENTER_RAD` 和 `POS_LOCK_EXIT_RAD` 是锁定状态阈值，不再表示“控制死区”。
- 锁定区内仍然保留位置误差，不能把误差置零。
- 锁定区速度限幅过小会导致被推开后拉回慢；过大则到位附近可能动作过猛。
- 模式切换或停止时需要清 `s_position_lock_active`，避免下次启动继承旧锁定状态。

#### 3.11.5 位置锁定区速度积分漂移问题

现象：

- 位置锁定后，角度可能逐渐积分变大并超过目标角度。
- 表现为一开始已经锁住，但随后保持电流或速度环积分慢慢把电机推过目标。
- 位置环本身当前没有积分，因此漂移主要来自速度环积分。

原因判断：

- 锁定区内位置环只输出较小 `speed_ref`，速度环为了消除微小速度误差会继续积分。
- 当位置误差已经接近 0 时，速度积分如果仍在原方向，会继续输出 `iq_ref` 偏置。
- 若速度环死区较大，通用 PID 会把小速度误差置零，但已有积分仍参与输出，反而更难靠反向误差消掉积分。

修改/处理结果：

- 在 `Config.h` 中增加锁定区速度积分泄放参数：

```text
POS_LOCK_SPEED_I_REVERSE_LEAK_FACTOR
POS_LOCK_SPEED_I_CENTER_LEAK_RAD
POS_LOCK_SPEED_I_CENTER_LEAK_FACTOR
```

- 在位置锁定区内增加速度积分方向约束：

```text
如果 pos_error * speed_pid.integral < 0：
    说明速度积分正在把电机往目标外推，快速泄放
否则如果 abs(pos_error) 很小：
    对速度积分轻微泄放，避免长期堆住
```

- 该逻辑只在位置锁定区生效，不影响普通速度环模式。

注意事项：

- 该修改不是清空积分，而是有条件泄放，目的是保留负载保持力。
- 如果仍然漂过目标，可适当减小 `POS_LOCK_SPEED_I_REVERSE_LEAK_FACTOR` 或增大中心泄放范围。
- 如果带负载保持变软，可适当增大泄放系数或减小中心泄放范围。
- 后续仍建议把速度环硬死区减小到 0 或极小值，再观察锁定区积分是否更容易自然反向消除。

#### 3.11.6 速度环死区处理结论

现象：

- 速度环目标附近震荡时，直觉上会想增加速度死区。
- 但位置锁定区需要小速度误差也能产生保持力。
- 当前通用 PID 的死区实现是直接将 `abs(error) < deadband` 的误差置为 0。

原因判断：

- 对速度环而言，硬死区会让小误差不参与 P 和积分更新。
- 但是 PID 旧积分仍会参与输出，因此死区可能造成“误差不反向修正、积分仍在推”的问题。
- 当前已经增加了速度 P 项误差相关缩放、速度积分分离和锁定区积分泄放，因此不应再主要依赖硬死区抑制震荡。

修改/处理结果：

- 当前已明确建议：速度环死区应改为 0 或极小值。
- 但截至本节记录，代码中 `SPEED_DEADBAND_RAD_S` 是否最终改为 0 需要以当前 `Config.h` 为准，不能只凭记忆判断。

注意事项：

- 如果 `SPEED_DEADBAND_RAD_S` 仍为较大值，调位置锁定时必须把它作为重点风险项。
- 推荐后续测试顺序：

```text
先记录当前速度环死区
再尝试 0.05 rad/s
再尝试 0.0 rad/s
比较锁定区保持力、速度噪声和积分漂移
```

- 改死区前后必须同时观察 `speed_error`、速度 P 项、速度 I 项、`iq_ref` 和实际角度漂移。

#### 3.11.7 三电机同时闭环的计算负载风险

现象：

- 当前单电机 2 号链路已经能够较稳定驱动。
- 但三电机同时运行时，需要同时承担三路 16 kHz 电流环、三路速度环、三路位置环和 SPI 编码器采样。
- 单电机能跑通不代表三电机同时闭环一定可靠。

原因判断：

- 三电机 16 kHz 电流环意味着每秒约 48k 次电流测量、PID、FOC 和 CCR 更新。
- SPI3 若作为多编码器共享总线，三路编码器不能同时读，必须排队调度。
- 电流环电角度不能每次都等待 SPI 新数据，应使用最近角度缓存和速度预测。
- 当前很多优化主要围绕 motor2 / TIM20 / ADC1 / encoder3 做过，motor0 和 motor1 的快环链路仍需逐个验证。

修改/处理结果：

- 当前尚未把三电机同时闭环作为代码主线实现。
- 已形成测试策略：

```text
阶段1：三电机分别单独跑通
阶段2：三电机只开电流采样和编码器采样，不输出 PWM
阶段3：三电机低电流电流环，不开速度/位置环
阶段4：三电机低速速度环
阶段5：三电机位置环和上层帧调度
```

- 建议后续增加运行时负载观测：电流环执行耗时、SPI 一轮读取耗时、TIM7 是否丢周期、各电机 update_count 和 encoder error count。

注意事项：

- 不要因为单电机稳定就直接三电机高速位置闭环。
- 三电机编码器采样频率不应简单等于电流环频率。
- 推荐结构：

```text
电流环：PWM/ADC 同步，高频
编码器：SPI 轮询调度，中频
速度环：约 1 kHz 或更低
位置环：约 200-400 Hz
```

- 三电机同时运行时，VOFA 发送频率和通道数量必须降低，否则会干扰实时判断。

#### 3.11.8 多电机位置帧序列和路径问题

现象：

- 软体机构控制不是简单把三个电机直接移动到最终位置。
- 例如：

```text
frame1: M0 -> 3 rad, M1 -> -1 rad, M2 -> -2 rad
frame2: M0 -> 2 rad, M1 -> -2 rad, M2 -> 0 rad
```

和直接执行：

```text
M0 -> 2 rad, M1 -> -2 rad, M2 -> 0 rad
```

最终位置可能相同，但中间路径、姿态、受力和缠绕方式完全不同。

原因判断：

- 拉索软体机器人具有明显路径依赖和接触/摩擦/弹性变形影响。
- 上层不能只保留最新目标位置，否则会跳过中间帧，丢失预期运动过程。
- 需要区分底层单电机伺服闭环和上层多电机运动帧调度。

修改/处理结果：

- 当前形成方案：后续应增加轻量 `motion_app` 或等价上层调度模块。
- 上层保存帧队列，每一帧包含三电机目标位置或更高层形态目标。
- 当前帧完成后再进入下一帧，而不是收到新目标就直接覆盖当前运动。

注意事项：

- CAN/FDCAN 协议后续应按“运动帧”设计，而不是只按单电机目标设计。
- 每帧至少应考虑：

```text
frame_id / seq
三电机目标或形态目标
速度限制
保持时间
是否等待全部到位
是否允许中途覆盖
急停/清队列标志
```

- 对拉索机构而言，中间帧本身就是动作的一部分，不能被优化掉。

#### 3.11.9 三线机构的 alpha/beta/common 和等效螺旋参数

现象：

- 用户提出三根拉线是否像三相电流一样有关系，是否可以通过两根线重构第三根线。
- 进一步讨论到：中间弹性层放松线缆后整体更直，表现为等效对数螺旋参数变大；三线拉直趋近于直线；单根线强拉趋近设计时的卷曲螺旋。

原因判断：

- 如果三根线在截面上约 120 度均匀分布，可以把三根线长度变化分解为：

```text
alpha：二维弯曲分量之一
beta：二维弯曲分量之二
common：三线共同收放/预紧分量
```

- 这和 FOC 中三相到 alpha/beta 的思想类似，但物理含义不同。
- 三线理论上可分解为两个差动弯曲自由度加一个共同预紧自由度；不建议简单省掉第三根线，因为第三根线对预紧、防松弛、刚度和抓握力很重要。

修改/处理结果：

- 当前只是控制建模方案讨论，尚未写入代码。
- 推荐上层形态控制变量从直接三电机位置，逐步抽象为：

```text
bend_dir：卷曲方向
bend_amount：卷曲程度/等效曲率强度
common：三线共同预紧/刚度
```

- 三线目标可以用类似变换生成：

```text
alpha = bend_amount * cos(bend_dir)
beta  = bend_amount * sin(bend_dir)

l0 = common + alpha
l1 = common - 0.5 * alpha + 0.866 * beta
l2 = common - 0.5 * alpha - 0.866 * beta
```

- 对于论文中的对数螺旋参数，建议区分：

```text
b_design：打印结构的几何设计参数
B_eff：当前形态表现出来的等效螺旋参数
u = 1 / B_eff：更适合作为控制变量的卷曲强度
```

注意事项：

- `b_design` 不应被当成电机实时直接控制量，它主要由结构几何决定。
- `B_eff` 或 `u` 可以作为当前形态的等效描述，但需要通过视觉、传感或实验标定建立线长到形态的映射。
- 三线同拉/同放不只是“位置变化”，还会改变预紧、刚度、抗松弛和抓握力基线。
- 当前阶段最实用的下一步不是复杂逆运动学，而是先标定：

```text
电机角度 -> 线长变化
线长差动 -> bend_dir / bend_amount / B_eff
common -> 线张力 / 刚度 / 抓握力
```

---

## 4. 当前主要困难

当前项目已经进入真实硬件 FOC 联调阶段，主要困难集中在以下几类。

### 4.1 电流采样真实性

现象：

- 空载时电流看起来较正常。
- 堵转或负载时三相电流波形可能畸变。
- 某些情况下 `ia + ib + ic` 不接近 0。

可能原因：

- 低侧采样窗口不足。
- ADC 触发点靠近开关边沿、死区或振铃区。
- 采样电阻没有 Kelvin 连接，地噪声影响采样。
- duty 过大或过小导致某相不可测。

当前处理：

- 限制 duty 范围。
- 尝试固定中点采样和动态采样点。
- 引入三相电流重构思路。

仍需验证：

- 不同转速、不同负载下 raw 是否可信。
- 堵转时三相电流和是否合理。

### 4.2 电角度 offset 精度

现象：

- 开环可以转。
- 带一点负载或手动阻挡时，有时像一个极一个极吸附。
- iq/id 可能存在耦合。

可能原因：

- offset 校准不够准。
- 编码器方向或极对数使用错误。
- Park/反 Park 符号或相序不一致。
- 校准时转子没有真正稳定吸附。

当前处理：

- 回退到单点 d 轴吸附校准。
- 使用 VOFA 观察电角度、offset、id/iq。

仍需验证：

- 校准后给 iq 时，id 是否保持接近 0。
- 正反方向转动时，iq/id 是否一致。

### 4.3 快环计算负载

现象：

- 电流环放 ADC 回调后电机更稳。
- 但系统响应变卡，VOFA 和按键可能变慢。
- 分频后系统压力下降，但电机可能变抖。

当前处理：

- 减少快环通用函数调用。
- 直接写 TIM20 CCR。
- 缓存固定寄存器值。
- 减少不必要的编码器更新。

仍需验证：

- 单电机快环 CPU 占用。
- 三电机同时闭环是否可承受。
- 是否需要进一步拆分高频内环和低频外环。

### 4.4 DRV 和功率级参数

现象：

- 曾出现 VDS/OCP 报错。
- 某些相曾经单独报错。
- 电机负载下平滑性仍不理想。

当前处理：

- 修正 SPI 配置。
- 读回寄存器确认配置。
- 当前为 6x PWM。
- 目前 TIM20 MCU 死区约 400ns，DRV 内部死区约 100ns。

仍需验证：

- 死区是否过长。
- 栅极驱动电流是否合适。
- OCP/VDS 阈值最终配置。

---

## 5. 当前建议调试顺序

为了避免多个问题叠加，后续建议按下面顺序推进。

### 5.1 先确认单电机基础链路

检查项：

- 编码器角度连续。
- 编码器 valid 稳定。
- DRV 无故障。
- PWM CCR 正常变化。
- ADC raw 正常更新。

### 5.2 再确认 offset 和相序

检查项：

- 单点校准能稳定完成。
- 校准后电角度连续。
- 给定小 iq 时电机方向符合预期。
- `id` 不应明显被激发。

### 5.3 再确认电流采样

检查项：

- raw 不削顶。
- 三相电流和接近 0。
- 堵转时电流波形仍可信。
- 不同 duty 下采样不失真。

### 5.4 再调电流环

检查项：

- 从小 iq_ref 开始。
- 限制 vd/vq 输出。
- 限制积分。
- 观察 id/iq、vd/vq、三相电流。

### 5.5 最后调速度环和位置环

检查项：

- 速度环先低速小目标。
- 速度环输出只作为 iq_ref。
- 位置环输出只作为 speed_ref。
- 每一层都有限幅。

---

## 6. 当前未解决问题清单

| 编号 | 问题 | 当前判断 | 优先级 |
|---|---|---|---|
| 1 | 负载下电机卡顿 | 当前电流环死区过大问题已修正，继续观察速度环/位置环接入后的负载表现 | 中 |
| 2 | 堵转时电流波形失真 | 低侧采样窗口和硬件采样质量风险 | 高 |
| 3 | 电流环 iq/id 抖动 | 已确认过大死区是空载规律震荡主因之一，当前已明显改善 | 中 |
| 4 | 快环过重 | 单电机已感受到压力，三电机风险更高 | 高 |
| 5 | 速度环未稳定调试 | 依赖电流环先稳定 | 中 |
| 6 | 位置环未实机验证 | 后续阶段处理 | 中 |
| 7 | 三电机并行未验证 | 需要单电机稳定后扩展 | 高 |
| 8 | FDCAN 通信未实现 | 控制链路稳定后再做 | 低 |
| 9 | 完整故障状态机未实现 | 当前仍以调试为主 | 中 |

---

## 7. 下一阶段目标

短期目标：

```text
让单电机在低速、轻负载、堵转短时状态下电流环稳定可控。
```

具体任务：

1. 固定当前单电机硬件映射。
2. 验证编码器角度和 offset。
3. 验证三相电流采样真实性。
4. 降低电流环 PID 参数，从保守值重新调。
5. 检查死区时间是否需要减小。
6. 验证堵转短时电流是否受控。
7. 电流环稳定后再恢复速度环测试。

中期目标：

```text
完成单电机电流环 + 速度环 + 位置环的基础闭环。
```

长期目标：

```text
扩展到三电机统一调度，并接入 FDCAN 主控通信和完整保护状态机。
```

---

## 8. 追加记录模板

后续每次遇到重要问题，可以按这个格式追加。

```markdown
### YYYY-MM-DD 问题标题

现象：

- 

初步判断：

- 

检查过程：

- 

修改内容：

- 

结果：

- 

遗留问题：

- 
```

---

## 9. 当前一句话总结

目前工程已经从“软件框架搭建”进入“单电机真实 FOC 联调”阶段。  
开环、DRV、编码器、ADC、电流环都已经跑通基础链路，但要达到负载下平滑稳定，还需要继续围绕电角度 offset、电流采样真实性、低侧采样窗口、死区和快环性能做集中优化。

---

## 10. 2026-05 至 2026-06 关键调试补充记录

本节补充 2026 年 5 月到 6 月期间，单电机 FOC 联调、4010 新电机适配、三电机迁移过程中遇到的问题、处理方法和当前结果。
日期按 Git 快照、工程修改节点和调试对话时间记录；部分问题持续多天出现，因此用“前后”标注。

---

### 2026-05-17 前后：电流环基础链路与电流采样混乱

现象：

- 电流环开始运行后，`id/iq` 波形不稳定。
- 三相电流 raw 和重构后的电流值在 VOFA 中表现混乱。
- 电机运行时像步进电机一样抖动，单独给小电流也不够平滑。
- 一开始只在电流环启动后采样电流，导致上电静态下无法提前判断 ADC 是否正常。

原因判断：

- 电流采样链路和控制链路耦合太紧，导致问题定位困难。
- 低侧采样在不同 PWM duty 下存在窗口不足的问题。
- 仅靠两相电流重构第三相时，`ia + ib + ic` 始终被强制接近 0，不能再用三相和是否为 0 判断采样真实性。
- ADC 原始值、零漂补偿值、重构值和 Park 后的 `id/iq` 混在一起看，容易误判。

解决方法：

- 将电流采样改为上电后就能持续观察，而不是只在电流环模式下采样。
- 增加 VOFA 电流主题，分别观察 raw、补偿后相电流、重构信息、`id/iq`。
- 明确三相电流重构逻辑：窗口不足的一相用另外两相重构。
- 引入 ADC 自校准和电流零漂校准流程，区分 STM32 ADC 校准、DRV CAL 和真实采样链路残差修正。

当前结果：

- 上电后可以直接通过 VOFA 检查电流 raw 和相电流。
- 电流环基础链路可运行，后续问题主要集中到采样窗口、重构相选择和 PID 参数。

注意事项：

- 两相重构第三相后，不能再用 `ia + ib + ic = 0` 作为采样有效性的唯一判断。
- 应重点看 raw 是否削顶、是否贴近 2048、是否有相位相关尖峰。

---

### 2026-05-20 前后：低侧采样窗口、动态 ADC 触发与重构相问题

现象：

- 转动时电流波形出现明显削顶，曾观察到接近 2048 的异常平台。
- `VOFA_TOPIC_PHASE_CURRENT` 中三相或重构项出现尖峰。
- 重构相选择在高速或 duty 变化较快时从阶梯状变成尖峰状，导致 `id` 不稳定。
- 关闭重构后，电流环更容易飞掉，说明低侧采样窗口确实存在问题。

原因判断：

- ADC 采样点靠近 PWM 边沿、死区或振铃区时，低侧采样不可信。
- duty 最大的一相低侧导通窗口最短，容易成为需要重构的相。
- 重构相在边界附近频繁切换，会把采样误差周期性注入 `id/iq`。
- 空转时电流小，采样误差占比更高；堵转或加负载后电流变大，误差比例下降，因此看起来更稳定。

解决方法：

- 修改动态 ADC 触发 CCR，根据 duty 和重构相计算下一周期采样点。
- 增加 ADC 触发保护边界 `guard`，避开 PWM 边沿区域。
- 增加重构相滞回和最小保持周期，减少边界频繁切换。
- 增加 VOFA 诊断，观察重构相、ADC 触发 CCR、重构使能状态。

当前结果：

- 重构逻辑对电流环稳定性是必要的。
- 动态采样点和重构相选择仍需要结合实际硬件、转速和负载继续验证。

注意事项：

- 重构相出现尖峰不一定是逻辑错误，高速时 VOFA 显示可能因为采样频率不足而显得尖锐。
- 但如果 `id` 和重构相切换严格同步抖动，应优先检查 ADC 触发点和重构相切换策略。

---

### 2026-05-20 至 2026-05-31：电角度校准、id 震荡与电流环死区

现象：

- 电角度校准后，`id` 反而出现周期性震荡。
- 不校准时三相电流看起来更像正弦，但这不能作为最终控制方案。
- 空转时 `id` 抖动明显，按住电机或加负载后电流变稳定。
- `vd/vq` 看起来相对稳定，但 `id/iq` 仍然抖动。

原因判断：

- 初期怀疑电角度 offset 不准、编码器滞后、反电动势补偿不足。
- 尝试电角度预测、补偿增益和反电动势补偿后，效果不明显。
- 后续确认一个关键原因：电流环死区设置过大，导致小误差区域控制输出不连续，引发空载规律震荡。

解决方法：

- 修正 FOC 电角度校准逻辑。
- 增加电角度预测和调试通道，观察预测补偿量。
- 尝试反电动势补偿，但未作为最终主解法。
- 缩小电流环死区，使小电流误差附近仍能连续调节。

当前结果：

- 电流环空载稳定性明显改善。
- 重要结论：`id` 周期性震荡不能只盯电角度，电流环死区和采样误差同样可能是主因。

注意事项：

- 不校准时波形看似正常，不代表 FOC 角度正确。
- 有负载变稳定时，不能直接判断角度正确；也可能只是电流变大后采样误差比例下降。

---

### 2026-05-31 前后：4010 新电机参数适配

现象：

- 更换 4010 电机后，原参数不再完全适用。
- 电角度校准时实际方向与预期相反。
- 空转时 `id` 跳变仍明显，电流环参数需要重新估算。

电机参数记录：

```text
型号：JZ4010
极槽：24N22P
电压范围：12~24V
相电阻：约 8.6 ohm
扭矩常数：约 0.21 N*m/A
最大瞬间电流：2 A
相电感：调试中曾按约 4.76 mH 估算
```

原因判断：

- 新电机电阻、电感、极对数、转动惯量和原电机不同。
- 原电流环 PI 参数和限幅不能直接照搬。
- 反电动势补偿建模需要可靠的 `Ld/Lq/we/Kv`，当前参数不完整，补偿只能作为小增益试探。

解决方法：

- 修改新电机相关配置和方向参数。
- 重新估算电流环参数，并从保守值开始调试。
- 尝试反电动势补偿和补偿增益，但实际改善有限。
- 仍以电流采样质量、电角度校准和电流环死区为主要优化方向。

当前结果：

- 4010 电机单电流环已经能稳定运行。
- 后续负载下仍需重新整定电流环、速度环和位置环参数。

注意事项：

- 新电机参数不要只按理论值一次写死，应保留调试余量。
- 反电动势补偿不能替代基础电流环稳定性。

---

### 2026-05-31 至 2026-06-03：速度环震荡、速度估计与位置环锁定

现象：

- 速度环接入后，电机会出现周期性震荡和啸叫。
- 只给很小 P 项，速度反馈仍然在目标附近上下波动。
- `iq_ref` 呈规律性波浪，速度环跟踪慢但又容易震荡。
- 位置环到目标附近时，目标速度在死区边缘震荡，伺服锁定不够硬。
- 位置死区内直接清零会泄力，后续带负载存在风险。

原因判断：

- 单次角度差分速度噪声较大。
- 速度环 P 项在目标附近来回反向输出，是震荡的重要来源。
- I 项相对平稳，但积分过强会导致响应慢或堵转后恢复差。
- 位置环简单死区不适合伺服锁定，容易出现边缘抖动和锁不住。

解决方法：

- 将速度计算改为一段时间内累计角度差 / 累计真实 DWT 时间的平均速度。
- TIM7 负责低频速度外环，SPI 回调只更新角度缓存和样本累计。
- 增加 `iq_ref` 低通。
- 速度环加入积分分离、泄放和小误差 P 衰减。
- 位置环从“死区”思路改为“锁定区”，并加入阻尼和积分泄放。

当前结果：

- 单电机速度环震荡降低到可接受范围。
- 位置环基本完成单电机验证，但带负载锁定安全性仍需实测。

注意事项：

- 速度环和位置环不要直接在高频 ADC 回调中执行。
- 速度环输出只应改变 `iq_ref`，位置环输出只应改变 `speed_ref`。
- 位置环上负载前，不能用“到位清零”这种会突然泄力的策略。

---

### 2026-06-03 至 2026-06-14：三电机框架迁移前的快环风险

现象：

- 单电机 motor2 已经基本可控，但三电机同时运行存在实时负载风险。
- 原来很多逻辑固定在 TIM20 / ADC1 / encoder3。
- 如果三电机都跑 16kHz 电流环，再叠加速度环、位置环和 SPI 编码器读取，可能导致中断负载过重。

原因判断：

- 快环中不必要的 ID 映射、函数跳转和重复三角函数会放大 CPU 开销。
- 原设计中部分通用保护判断在高频路径重复执行，调试阶段可以逐步精简。
- 三路编码器共用 SPI3，总线必须串行调度。

解决方法：

- 在 `motor_t` 中绑定每台电机自己的 ADC、编码器、PWM CCR、ADC 触发 CCR。
- 将 motor2 专用快环扩展为 `Motor_Core_RunCurrentFastLoopFromAdc(motor_id, dt)`。
- 保留旧 motor2 入口作为兼容调试接口。
- FOC 快环中复用同一组 `sin/cos`，避免 Park 和 InvPark 重复计算三角函数。

当前结果：

- 三路电流快环的软件结构已经具备。
- 是否能三路同时稳定运行仍需上板验证。

注意事项：

- 三电机迁移不能简单复制 motor2 逻辑，应先绑定资源，再让快环读绑定字段。
- 快环优化必须保持 FOC 限幅、SVPWM 和 duty 写回逻辑不变。

---

### 2026-06-14 前后：MT6816 编码器 SPI 读取与硬件风险

现象：

- 静止时编码器基本正常，转动时 parity/frame/no_mag 错误明显增加。
- 曾出现角度从约 2000 跳到 10000 的异常，导致电机震动。
- 换编码器芯片后部分异常消失。
- 多个编码器接入同一 SPI3 MISO 后，即使只读取一路，也可能疯狂报帧校验错误。
- 不接 MISO 或不接 MOSI/SCK 时，MISO 电平表现异常，说明硬件总线状态需要重点检查。

原因判断：

- 曾怀疑 SPI 频率、CS 时序、DMA 被中断打断、高低字节非同一帧。
- MT6816 的 0x03/0x04 角度寄存器读取方式需要严格按手册确认。
- 多编码器 MISO 并接要求未选中器件真正高阻，否则会互相拉扯。
- 线太长、上拉不足、CS 未可靠释放都可能导致校验错误。

解决方法：

- 对比 3 字节 burst read、4 字节读法、两次分开读 0x03/0x04。
- 采用 MT6816 burst read：`0x83 0x00 0x00`，解析 `rx[1]` 和 `rx[2]`。
- 保留分开读模式开关，便于后续回退。
- 优化 CS 建立/保持时间。
- SPI3 多次尝试不同分频，当前更关注总线硬件和调度。

当前结果：

- 单编码器读取可以稳定。
- 三编码器共总线仍需结合硬件高阻、线长和片选电平继续验证。

注意事项：

- 校验错误不一定是软件解析错误，也可能是 MISO 硬件总线冲突。
- 多编码器并接时，必须确认未选中器件 MISO 是否高阻。

---

### 2026-06-21：三路编码器 Pending 调度

现象：

- 原来三路编码器由 ADC1 统一触发 `SPI_Encoder_Start_Update_All_DMA()`。
- 三电机迁移后，每个电机的 ADC 回调都应该请求自己的编码器刷新。
- 但 SPI3 是共享总线，三个 ADC 回调不能同时启动 SPI DMA。
- DMA 完成后如果连续拉起下一路，会导致 SPI DMA 中断链过重，并且编码器刷新频率不再受控。

原因判断：

- 编码器请求源应该拆到 ADC4/ADC3/ADC1，但 SPI3 启动必须集中串行。
- pending 适合表示“该路需要刷新一次最新角度”，不适合做无限队列。
- 实际频率仍应由 ADC 分频控制，而不是 SPI 总线最大吞吐控制。

解决方法：

- 新增 `SPI_Encoder_Request_Update_DMA()`：只置 pending，不启动 SPI。
- 新增 `SPI_Encoder_ServicePendingOnce()`：SPI 空闲时最多启动一路 pending。
- ADC4/ADC3/ADC1 分别每 2 次请求 encoder1/encoder2/encoder3，目标约 8kHz。
- SPI DMA 完成回调只释放 CS、解析帧、更新缓存、清 busy，不自动连续启动下一路。
- 保留旧 `Start_Update_All_DMA()` 和 `Start_Update_One_DMA()` 调试接口。

当前结果：

- 三路编码器刷新结构已经从“ADC1 统一触发三路”改为“三路 ADC 请求 + SPI3 串行服务”。
- `git diff --check` 已通过。

注意事项：

- 如果 pending overwrite 或 missed 计数持续增长，说明 SPI 读取频率过高或总线异常。
- 后续需要把 pending/missed/valid 加到 VOFA 诊断中。

---

### 2026-06-21：TIM7 速度环/位置环 selected motor 迁移

现象：

- TIM7 速度环和位置环仍固定服务 motor2 / encoder3。
- 当选择 motor0 或 motor1 调试时，速度计算和位置目标仍可能来自 encoder3。
- KEY2 位置目标曾固定使用 `SPI_Encoder_Get_Total_Angle(encoder_id_3)`。

原因判断：

- 电流快环已经三路化，但外环还停留在单 motor2 调试阶段。
- 如果不先做 selected motor 迁移，后续调 motor0/motor1 的速度环会被错误编码器数据污染。

解决方法：

- 新增 `Motor_Core_GetBoundEncoderId(motor_id)`。
- TIM7 中读取 `s_selected_motor_id`，并使用该电机绑定的编码器计算速度。
- 速度环 dt、速度分频、位置分频改为按 motor_id 独立保存。
- KEY2 位置目标改为当前选中电机绑定编码器的当前角度 + delta。

当前结果：

- selected motor 的速度环/位置环调度已经迁移。
- 关键路径中不再固定调用 `encoder_id_3` 和 `2U`。
- 当前仍不是三路 all motors 外环。

注意事项：

- 下一步应先逐个选择 motor0/motor1/motor2 验证速度环和位置环。
- KEY1 的 VOFA 记录仍有固定 TIM20/encoder3 的调试显示残留，需要后续修正。

---

### 2026-06-21 当前待办更新

短期验证顺序：

1. 使用 `VOFA_TOPIC_ENCODER_ALL` 查看三路编码器 raw、angle、valid 是否稳定。
2. 分别手动转动三路编码器，确认没有串路。
3. 观察 SPI DMA missed / pending overwrite 是否持续增长。
4. 单独选择 motor2，确认修改后速度环/位置环表现与之前一致。
5. 分别选择 motor0、motor1，验证电流环、速度环、位置环是否使用对应编码器。
6. 修正 KEY1 调试记录，使其显示 selected motor，而不是固定 TIM20/encoder3。
7. 三路单独验证后，再考虑 TIM7 中循环 all motors 外环。

当前最高风险：

- 三路 ADC 回调 + 三路电流快环 + SPI3 编码器 pending 调度的总实时负载。
- 三编码器 MISO 并接的硬件可靠性。
- 低侧采样窗口在三路同时运行、负载变化和较高 duty 下的真实性。

---

## 11. 2026-06-22 至 2026-07-18 关键调试续记

本节从 2026-06-21 的三路编码器 pending 调度和 selected motor 外环迁移之后继续记录。

记录原则：

- 每个问题均区分“现象、原因判断、解决方法、当前结果、注意事项”。
- 调试中试过但无效的方案也保留，防止后续重复走弯路。
- “当前结果”只描述已经通过代码或实机验证的状态；没有完成实机验证的内容明确标为待验证。

---

### 2026-06-22 至 2026-06-28：三路高速电流环迁移与实时负载评估

现象：

- 之前主要围绕电机3，即代码中的 `motor2`，单独优化电流快环，其余两台电机仍有旧入口或不完整迁移。
- 三台电机逐步同时开启时，单台运行正常，增加到两台或三台后出现程序卡死或控制停止。
- DWT 观测到单台完整电流快环约为 23us，但三路在原高频配置下没有足够的中断和主循环余量。
- 将 PWM 和电流环目标频率尝试提高到 12kHz 时仍存在时序和编译配置风险；更高频率下三路同时运行不稳定。

原因判断：

- 三路 ADC 回调、三路电流环、共享 SPI3 编码器 DMA、TIM7 外环和 VOFA 调试叠加后，最坏执行时间远高于单路测量值。
- 三台电机虽然拥有独立 PWM 和 ADC，但 CPU、SPI3、DMA 中断和部分数学运算仍然共享。
- 原代码中存在重复三角函数、重复电流处理、通用 ID 查询和高频路径中的冗余有效性判断。
- 三路控制不能共用一个 DWT `last_cycles`，否则其中一路更新会污染另外两路的实际 `dt`。

解决方法：

- 将三路电机分别绑定到各自 ADC、PWM、编码器和 ADC 触发资源。
- ADC4、ADC3、ADC1 分别驱动电机1、电机2、电机3的电流快环。
- 每台电机使用独立 DWT 时间戳，`dt` 表示该电机两次实际执行电流环之间的真实时间。
- Park 和 InvPark 复用同一次计算得到的 `sin/cos`，去除重复角度计算。
- 减少快环中的 ID 查询、重复绑定检查和无意义的通用保护判断。
- 增加 DWT 快环耗时观测，分别测量单路和多路运行时间。
- 最终将三路 PWM 和电流环频率统一为 10kHz，以换取稳定的实时余量。

当前结果：

- 三台电机均具备独立的 ADC 同步电流快环入口。
- 单路完整快环实测约 23us，10kHz 配置下的单路周期预算为 100us。
- 16kHz/12kHz 三路同时运行存在明显风险，10kHz 是当前实机使用的稳定配置。
- 当前 `Config.h` 中 `PWM_FREQ` 和 `MOTOR_CURRENT_LOOP_FREQ_HZ` 均按 10kHz 语义运行。

注意事项：

- 23us 是单路观测值，不能直接认为三路总耗时就是严格的 69us；中断抢占、SPI等待和缓存行为会增加最坏耗时。
- 修改 PWM 频率后，必须同步检查 TIM1/TIM8/TIM20、ADC触发点、电流环 `dt` 和速度/位置环分频。
- PID连续时间参数原则上不应只因采样频率变化而机械倍乘，但离散积分、滤波系数和限幅仍要重新确认。

---

### 2026-06-22 至 2026-06-28：CubeMX 中三路 PWM 与 ADC 触发关系校正

现象：

- 电机1和电机2最初出现吸附、震荡和无法正常转动，而电机3相对正常。
- CubeMX 中 TIM1、TIM8 的 ADC 触发选项不直观，曾误以为缺少与 TIM20 CH4 相同的触发方式。
- 重新生成代码后，需要确认定时器通道、ADC Rank、NVIC优先级和 IOC 文件没有被误改。

原因判断：

- 三台电机的相线输出、低侧采样通道和 ADC Rank 必须严格一一对应。
- 电机1、电机2的 PWM 通道与采样引脚对应关系曾存在理解偏差。
- TIM20 的第三相使用 CH4，而 TIM1/TIM8 的三相主输出通道组合不同，不能只按通道编号机械复制。

解决方法：

- 按原理图重新核对三路 PWM 引脚、互补输出和三相采样引脚。
- 电机1按 PE12/PE13、PE11/PE10、PE9/PE8 对应 PD8、PD9、PD10重新核对。
- 电机2按 PC12/PC8、PC11/PC7、PC10/PC6 对应 PD11、PD12、PD13重新核对。
- 电机3保持已经验证的 TIM20/ADC1 对应关系。
- CubeMX重新生成后检查 `tim.c`、`adc.c`、`dma.c`、`stm32g4xx_it.c` 和 IOC 的差异。

当前结果：

- 三路 PWM、ADC 和电机对象的资源绑定已经完成。
- 电机1、电机2在修正对应关系后不再表现为最初的强烈吸附震荡。
- 2026-06-28 保存了 `Save motor direction open-loop debug state` 工程节点。

注意事项：

- CubeMX 的 ADC Rank 页面主要显示通道和Rank，具体引脚需要回到 Pinout 或查看生成的 GPIO/ADC 通道定义。
- 每次重新生成代码后都要重新检查 USER CODE 区和 Keil 工程源文件列表。

---

### 2026-06-28 至 2026-06-29：三电机校正、电角度微调与方向统一

现象：

- 不校正时部分电机能够转动，执行校正后反而吸附或无法继续控制。
- 三台电机的机械转向、编码器方向、速度反馈方向和电角度微调曾相互叠加，导致“改一个方向后另一层又反掉”。
- 校正流程最初只完整服务单台电机，扩展为三台后曾出现状态未释放、校正完成后 PWM 中性输出仍保持等问题。
- 部分电机需要在校正结果中并入 90度电角度微调，另一些电机使用 0度时更正常。

原因判断：

- 机械反馈符号错误会把速度环或位置环变成正反馈。
- FOC电角度微调错误会造成吸附、发热、力矩偏小或类似步进电机的卡顿，不能用速度/位置反馈符号代替。
- 校正结束后如果没有正确停止 PWM、清理校正状态并恢复控制入口，会出现“校正后按键不能转”。
- 将方向修正分散在编码器、速度反馈、位置误差、CAN命令和最终目标多个位置，容易重复取反。

解决方法：

- 三台电机按顺序执行电角度校正，并在上电初始化后自动连续校正两轮。
- 每台电机单独保存校正得到的电角度 offset，禁止复用最后一台电机的结果。
- 电角度微调只在校正结果写入时一次性并入，不在每次 FOC 快环中重复计算。
- 将机械闭环反馈符号和 FOC 电角度微调分开管理。
- 尽量把命令方向修正集中到单一出口，减少 CAN、按键和映射层重复取反。
- 使用 KEY2 单电机测试宏，在电流环、速度环和位置环之间逐级验证。

当前结果：

- 三台电机能够分别完成校正，并具备各自独立的 offset。
- 上电自动校正轮数当前为 `MAIN_AUTO_FOC_CALIB_ROUNDS = 2U`。
- 三电机方向和电角度参数后来进一步迁移到板级配置文件中，不再假设所有驱动板完全一致。
- 2026-06-29 保存了 `Save three motor position control baseline`，表示三台电机位置控制主链路已经建立。

注意事项：

- `ENCODER_DIR_Mx`、`MOTORx_MECH_FB_SIGN` 和 `MOTORx_FOC_ELEC_TRIM_RAD` 作用不同，不能用其中一个盲目补偿另一个。
- 当前电角度校正辅助公式与注释中的正负号仍存在需要复核的历史疑点，列入后续高优先级检查项。

---

### 2026-06-28 至 2026-06-29：速度环与位置环迁移到三台电机

现象：

- 单台速度环调通后，另外两台电机仍可能使用旧的编码器、旧的反馈符号或共享外环状态。
- 大位置误差时，位置环会突然给出较大目标速度，切回近距离控制时又会发生速度突变和震荡。
- 到达锁定区边缘时，斜坡策略切换导致目标速度跳变。
- 速度环大误差完全禁止积分时，带载情况下可能长期卡在 P 项饱和区；完全不泄放又会造成超调。

原因判断：

- 位置环、速度环和电流环的状态必须按电机独立保存。
- 远距离运动适合限速巡航，接近目标后才适合由位置环连续减速和锁定。
- 大误差积分分离不能简单做成“积分开/关”，否则负载下可能没有足够稳态力矩。
- 锁定区与普通区域采用完全不同的速度命令处理，会在边界产生不连续。

解决方法：

- TIM7外环从 selected motor 逐步迁移为按活动 mask 更新三台电机。
- 每台电机单独保存速度计算累计量、速度PID、位置PID、斜坡状态和目标位置。
- 远距离位置误差采用巡航速度，接近目标后切回位置环，并设置进入/退出滞回。
- 非锁定区使用目标速度斜坡；锁定区仍保持闭环，不再简单清空输出泄力。
- 速度环改为大误差积分降额、小误差正常积分，并保留受限的反向泄放。
- 三电机位置目标通过统一函数一次写入，保证同一动作同时更新三路目标。

当前结果：

- 三台电机均已接入电流环、速度环和位置环。
- KEY2曾用于三台电机同时位置控制，也保留单电机宏选择用于板级调试。
- 位置环可完成远距离巡航、近距离减速和锁定，但最终负载下的锁定参数仍需逐板调整。

注意事项：

- 到达目标不能直接把三环状态全部清零，否则带负载机构会突然泄力。
- 新目标覆盖旧目标时，三台电机必须在同一动作边界同步更新，不能逐台形成不同起始时刻。

---

### 2026-06-30 至 2026-07-02：G4 与 H7 的 CAN FD 控制链路建立

现象：

- H7发送位置命令后，G4能收到 `cmd/flags/mask`，PWM也能启动，但电机最初不转或只有轻微声音。
- 按键控制相同目标时较稳定，CAN控制出现超调、不同步或只有一两台电机先动。
- 连续快速发送相对位置命令时，目标可能被重复叠加。

原因判断：

- CAN应用层维护的 PWM mask 最初没有接入 `main.c` 中已经验证的活动电机 mask。
- 结果是 CAN 命令启动了 PWM，但 TIM7外环和ADC电流快环没有真正进入运行状态。
- CAN新动作到来时，旧位置斜坡、速度PID积分、位置PID状态和目标缓存没有按动作边界处理。
- 相对位置命令如果因重发被重复应用，会把一次位移累加多次。

解决方法：

- 将按键活动 mask 与 CAN 活动 mask 合并，供 TIM7外环和三路ADC快环统一判断。
- CAN位置命令要求 `ENABLE + APPLY`，并以三电机 mask `0x07` 作为完整触手动作。
- 使用序列号识别新命令，防止相同相对目标重复执行。
- 新动作到来时三台电机同步更新目标，并只清理确实需要重启的斜坡/控制状态。
- 保留 STOP、绝对位置、相对位置、设置零点、回零和恢复控制语义。
- G4定期发送三台电机实际多圈位置状态，供H7维护上层绝对参考。

当前结果：

- H7到G4的 CAN FD+BRS 通讯、位置命令解析和G4状态回传已经打通。
- CAN启动的电机已经接入与按键相同的三环执行链路。
- 三台电机的新动作采用统一命令和统一应用时刻，不再有意按单台目标逐个启动。

注意事项：

- CAN通讯成功只说明帧到达，不能证明外环、快环和PWM状态已经全部接通。
- 相对位置命令必须具有去重语义；绝对位置命令可以覆盖目标，但仍要处理动作切换状态。
- 按键和CAN应最终进入同一控制执行入口，差别只保留在命令来源层。

---

### 2026-07-02 至 2026-07-06：HOME、ACTUAL 与 W25Q64 掉电恢复

现象：

- 需要在掉电后知道触手当前位置，并能够回到用户设定的初始形状。
- 早期方案曾把“设置零点”理解为直接把G4编码器当前位置清零，这与实际需求不符。
- `W25LOAD` 中 HOME 与 ACTUAL 不相同，但发送 HOME 命令后电机不转，容易误判为存储数据无效。
- 未断电时，H7缓存、G4状态和Flash中最后保存值可能处于不同更新时间。

原因判断：

- HOME是用户定义的机构初始参考，ACTUAL是持续变化的当前位置，两者生命周期不同。
- H7需要同时保存“初始参考”和“最近实际位置”，但不能每500ms重复写HOME。
- G4本身只负责闭环执行和上报实际多圈位置，不应该擅自重新定义H7的机构零点。
- HOME命令能否产生动作还取决于G4是否在线、恢复状态、控制mask和目标是否真正应用。

解决方法：

- W25Q64分别保存 HOME 记录和 ACTUAL 记录，并带序列号和有效性校验。
- 设置零点时只更新HOME；不修改G4编码器累计值，也不把G4内部位置强制清零。
- G4每100ms通过CAN状态帧发送三台电机实际多圈位置。
- H7每500ms在位置确有变化时保存ACTUAL，减少Flash擦写压力。
- 上电时读取最新有效HOME和ACTUAL，用于恢复上层坐标关系。
- 绝对位置控制相对于HOME解释；相对位置控制相对于最新ACTUAL解释。

当前结果：

- W25Q64基本读写测试通过。
- H7已具备HOME/ACTUAL分离保存、序列号选择和掉电恢复基础链路。
- G4状态帧以100ms周期提供位置，H7以500ms节拍进行ACTUAL持久化。

注意事项：

- HOME一般只在用户明确设置初始位置时写入，不能跟随ACTUAL周期更新。
- ACTUAL是掉电恢复参考，不等于重新校准编码器机械零点。
- 回零不转时要同时检查 `online`、状态帧新鲜度、命令序列号、控制mask和G4当前模式，不能只比较HOME与ACTUAL数值。

---

### 2026-07-02 至 2026-07-06：H7 手势识别与三拉索映射控制

现象：

- H7需要把VL53阵列和手势推理结果转换为三根拉索的目标位置。
- 仅使用三个电机目标角度难以表达弯曲方向、弯曲程度和整体预紧/刚度。
- 手在圆心附近轻微移动时，直接使用 `atan2` 会造成方向角快速跳变。
- 手突然离开检测区域时，不能让电机继续沿最后速度运动。
- 映射初期出现三台电机同向收缩、差动量没有形成预期弯曲方向，以及某台电机方向相反的问题。

原因判断：

- 三根拉索在截面上相隔120度，控制量应拆成差动分量和共同分量。
- `x/y` 适合只决定弯曲方向，抓握程度适合决定弯曲幅度，距离适合决定共同预紧或刚度。
- 中心区域的方向向量模长太小，角度本身没有可靠意义。
- 电机机械正方向与“放绳/收绳”物理方向必须在最终映射出口统一。

解决方法：

- 将三根线视为相隔120度的三个轴，使用方向投影生成三路差动量。
- `x/y` 经过中心死区和限幅后只决定单位方向，不直接决定弯曲幅度。
- `bend` 决定差动量幅值，`stiff` 决定三路共同收放量。
- 无手检测时保持当前目标，不继续生成新动作。
- 中心区域停留配合快速抓握识别虚拟按键；单次抓握窗口约1s，双击等待窗口后续缩短到约1.5s方向。
- 以约320mm为距离分区，组合形成不同选择/开关语义。
- 增大最大弯曲差动行程，曾将 `bend=100` 对应的最大差动目标提高到约4500控制单位。
- 电机方向差异尽量只在最终目标出口做一次修正。

当前结果：

- H7已经具备从手势/位置/距离到三电机目标的映射框架。
- 形成了 `x/y + bend + stiff` 四个上层控制量，并通过CAN FD发送三电机同步目标。
- 映射范围、每块触手的机械方向和最大安全行程仍需通过实物逐板标定。

注意事项：

- 三路差动量理论上应保持零和或固定共同量，整体同拉同放必须单独由 `stiff` 控制。
- 方向修正不能同时存在于H7映射、CAN命令和G4闭环反馈多个层级。
- 映射调试必须先用小幅度目标确认三根线的收放方向，再逐步增大 `bend` 和 `stiff`。

---

### 2026-07-02 至 2026-07-06：H7采集、训练与CubeAI部署问题

现象：

- VL53数据采集、CSV训练、holdout验证和CubeAI部署过程中出现数据路径、缓存、样本不均衡和推理占位符等问题。
- SD卡不存在或初始化失败时，部分流程可能阻塞。
- H7开启DCache后，DMA采集缓冲与CPU看到的数据可能不一致。
- 训练脚本中普通随机划分结果较好，但距离区间holdout更能暴露模型跨距离泛化问题。

原因判断：

- 随机holdout仍然使用同一CSV中的留出样本，不是“没有数据集的测试”。
- 数据采集质量、ROI、距离范围和类别平衡对结果影响大于盲目增加网络规模。
- DMA缓冲需要考虑Cache一致性，不能把旧缓存数据误认为传感器或模型错误。

解决方法：

- 建立独立训练脚本、数据目录和导出目录，命令行通过 `--csv` 指定数据集。
- 增加同划分CNN/MLP比较、距离holdout和位置ROI分析。
- 采集流程增加超时、重试和无SD卡情况下的可控退出。
- 使用自定义可控推理函数替换早期CubeAI占位调用，并保存部署检查点。
- 2026-07-02分别保存H743手势控制工程和CubeAI部署工程节点。

当前结果：

- H7已具备VL53采集、VOFA观察、CSV训练和嵌入式推理的完整基础链路。
- 模型训练和多距离泛化仍是持续优化项目，不视为已经最终定型。

注意事项：

- 训练准确率必须结合独立距离holdout、混淆矩阵和实机连续推理稳定性判断。
- 修改DMA缓冲或Cache策略后，需要同时验证采集值和推理输入是否一致。

---

### 2026-07-06 至 2026-07-12：多触手CAN节点与G4板级参数配置

现象：

- 新焊接的G4板使用同一套程序时，可能出现某台电机发热、吸附、扭矩不匹配或转向不同。
- 如果为每块板复制完整工程，后续修复很容易遗漏或产生多个不一致版本。
- H7需要区分多个触手的命令帧和状态帧。

原因判断：

- 即使原理图相同，不同板子的电机相序、编码器安装方向和电角度微调也可能不同。
- 这些差异应该是板级配置，不应该复制整套FOC和CAN实现。
- 所有G4共用同一CAN ID会导致命令和状态冲突。

解决方法：

- 增加 `G4_BOARD_PROFILE_ID` 和 `board_profiles.h`，集中保存每块驱动板的差异参数。
- 每块板单独配置 `MOTORx_MECH_FB_SIGN` 和 `MOTORx_FOC_ELEC_TRIM_RAD`。
- CAN命令ID按 `0x120 + board_id`，状态ID按 `0x180 + board_id` 分配。
- H7侧扩展为多触手节点管理，并保存四触手控制基线。
- 板级配置增加中文注释，明确参数作用和调试顺序。

当前结果：

- 2026-07-06保存G4/H7控制与手势更新节点。
- 2026-07-12保存 `Save four-tentacle control baseline`。
- 当前工程已具备1至4号G4板配置入口。
- 截至2026-07-18，当前 `Config.h` 选择的是 `G4_BOARD_PROFILE_ID = 4U`，烧录前必须确认目标板号。

注意事项：

- 板级 profile 只存硬件差异，不复制控制算法。
- 修改某块板参数前必须先确认正在编译的 `G4_BOARD_PROFILE_ID`，否则可能把测试固件烧到错误触手。
- 新板调试顺序应为DRV、编码器、校正、电流环、速度环、位置环，不能直接从多触手映射开始。

---

### 2026-07-13 至 2026-07-16：板2电机方向、力矩与CAN/按键差异排查

现象：

- 板2使用按键控制时，部分电机表现接近正常FOC；使用CAN位置控制时，电机1曾出现力矩变小、碰一下转一下和逐渐发热。
- 三台电机目标数值相同时，电机1机械方向与另外两台不一致。
- 仅修改H7手动命令层会使其他自动映射控制仍然反向。

原因判断：

- CAN与按键最终应共用同一G4三环，CAN本身不会改变FOC电角度。
- 如果只有一台电机发热或吸附，优先检查该电机的反馈符号、电角度trim、相序和采样，而不是把问题归因于CAN总线。
- 电机1方向修正如果只加在某条命令路径，会造成绝对、相对、映射和回零行为不一致。

解决方法：

- 对比按键和CAN经过的活动mask、模式设置、目标写入、PID状态和最终电机目标。
- 将单台电机机械方向修正集中到统一目标出口，避免每种命令分别处理。
- 板2的反馈方向和电角度微调独立保存在板级 profile 中。
- 使用小角度、低速度CAN相对位置命令验证三台电机的实际收绳/放绳方向。

当前结果：

- CAN与按键均进入同一G4控制执行链路。
- 板2的个性化方向和电角度参数已从通用逻辑中分离。
- 板2最终参数仍属于实机标定结果，不能直接复制到板3或板4。

注意事项：

- 目标角度方向错误通常只导致转向错误；碰一下转一下、发热和吸附更像FOC电角度、相序或电流采样问题。
- 调方向前先区分“闭环正反馈”和“FOC相位错误”，两者现象和修复位置不同。

---

### 2026-07-15 至 2026-07-18：板3单电机调试与电机3吸附问题

现象：

- 板3电机1、电机2可以正常或基本正常转动，电机3表现为强吸附、手转时像步进电机、力矩很轻或完全不响应。
- 修改电机3编码器方向和多组电角度微调后，现象没有出现根本变化。
- 更换DRV后现象仍相同，说明不能只归因于驱动芯片损坏。
- 自动校正看起来只完成两台或第三台校正不完整，但VOFA中的PWM使能和校正状态需要进一步区分。

原因判断：

- 单台电机异常而另外两台正常，优先检查该路PWM输出、相电流采样、ADC触发点、相序和板级焊接。
- 编码器方向修改对纯电流环/真正无编码器开环不应有影响；如果现象不变，编码器不是唯一根因。
- 电角度trim改动无效，说明可能存在缺相、采样相错误、校正公式或实际PWM未形成旋转电压矢量。

解决方法：

- KEY2改为单电机测试，通过 `MAIN_KEY2_SINGLE_TEST_MOTOR_ID` 在0/1/2之间选择。
- 在电流环、编码器参与开环、纯软件电角度开环和三环位置模式之间逐项切换排查。
- VOFA增加TIM20主/互补通道使能、CCER、三相CCR和ADC触发CCR观察。
- 检查DRV状态、编码器有效性、校正完成标志和三相电流。
- 试验结束后恢复三环位置模式，避免临时开环代码留在正式控制路径。

当前结果：

- TIM20三相主输出和互补输出从寄存器状态看均已开启。
- 观测到三相CCR不是完全相同的固定值，说明软件确实在生成三相调制量。
- 更换DRV和反转编码器均未消除电机3异常，因此这两项暂时不是首要根因。
- 纯软件角度开环测试没有得到正常连续转动，问题范围进一步收缩到PWM功率输出、相序、电流采样或硬件连接。

注意事项：

- “开环”必须区分仍使用编码器角度的电压模式和完全由软件累加电角度的真正无编码器开环。
- 开环电压过小可能无法克服齿槽、减速器和拉索负载，完全不动不能单独证明缺相；但强吸附仍提示旋转矢量没有正确建立。

---

### 2026-07-16 至 2026-07-18：电机3 B相电流长期处于中间值

现象：

- 在 `PHASE_CURRENT` 主题中，电机3的B相电流长期处于另外两相之间。
- 手动转动或使电机吸附时，B相有上升趋势，但很快被拉回中位。
- 另外两相呈明显切换变化，B相不像正常三相相差120度的波形。
- 旧板的电机1、电机2没有同样明显的问题。

原因判断：

- 如果显示的是重构后的三相电流，某一相被选为重构相时可能天然落在另外两相之间，因为它由 `-(Ia + Ic)` 得到。
- 如果B相无论扇区和重构选择如何都长期在中间，则需要检查B相ADC通道、运放输出、采样电阻、焊接和ADC Rank映射。
- 动态重构相选择、滞回和保持周期可能使某一相长时间被作为重构相，从而掩盖真实ADC波形。
- 采样点若落在低侧导通窗口外，也会让某一路实测值不可信并频繁回退到重构值。

解决方法：

- 同时观察原始三路ADC值、重构前电流、重构后电流、当前重构相ID和ADC触发CCR。
- 核对ADC1电机3三相通道与板上运放输出的实际连接。
- 使用万用表或示波器直接测B相电流采样运放输出，确认电压是否随相电流变化。
- 暂不通过继续增大PID或修改速度环掩盖采样异常。

当前结果：

- 已确认该现象不是简单更换DRV即可解决。
- 现有VOFA波形提示电机3 B相采样或重构链路仍需进一步硬件验证。
- 该问题截至2026-07-18仍属于未完全解决项。

注意事项：

- `PHASE_CURRENT` 若显示的是处理后的相电流，不能直接当作ADC引脚原始值。
- 下一次实测应固定记录：raw ADC、offset后电流、reconstruct phase、三相CCR、ADC trigger CCR，避免只看三条最终电流曲线。

---

### 2026-07-18：停止位置仍吸附，增加DRV COAST停机控制

现象：

- 单板不接CAN时，某台电机在第一次按KEY2之前就有吸附感。
- 位置控制运行期间现象反而减轻；再次按KEY2关闭控制后，又恢复吸附。
- 一台电机可以在重复流程后释放，另一台电机仍然保持吸附，怀疑三路PWM逐个停止存在状态差异。

原因判断：

- 仅停止定时器PWM并不一定保证功率级六个MOS立即进入高阻态。
- 高低侧输出脚、定时器空闲状态、DRV输入保持和CH4 ADC触发通道可能让桥臂处在非预期状态。
- 逐个停止三台PWM的执行时间不是主要矛盾；真正需要的是在停机语义上明确让DRV进入COAST。

解决方法：

- 在DRV8323 Driver Control寄存器中定义 `DRV8323_DRIVER_COAST = (1U << 2)`。
- `Motor_Core_StopPwmOutput()` 先置对应DRV的COAST位，再停止该电机PWM，使六个MOS进入高阻态。
- `Motor_Core_StartPwmOutput()` 先准备并启动PWM，再清除对应DRV的COAST位。
- 如果清除COAST失败，立即重新停止PWM，避免功率级输入状态不确定。

当前结果：

- COAST停机逻辑已经写入 `drv_drive.h` 和 `motor_core.c`。
- `git diff --check` 已通过。
- 尚未完成Keil全量编译和三块实机逐路验证，因此当前状态为“代码已修改，待实机确认”。

注意事项：

- COAST用于正常停机时释放电机，不代替过流、过温和紧急停机保护。
- 带负载触手是否允许自由滑行需要上层安全策略决定；某些工况可能需要制动或保持力矩，而不是COAST。
- 启动和停止均需要确认SPI写DRV寄存器成功，不能默默忽略失败状态。

---

### 2026-07-18 当前工程状态与后续验证顺序

当前已经完成：

1. 三台电机独立10kHz ADC同步电流快环。
2. 三台电机速度环和位置环主链路。
3. 三路编码器共享SPI3的pending串行调度。
4. 上电后三电机顺序自动校正两轮。
5. G4与H7的CAN FD位置命令和状态回传。
6. H7的HOME/ACTUAL掉电保存基础链路。
7. H7手势到三拉索目标的映射框架。
8. 四块G4板的CAN节点和板级参数配置框架。

当前代码调试配置：

- `G4_BOARD_PROFILE_ID = 4U`，当前编译目标为触手4配置。
- `PWM_FREQ = 10000`，电流环目标频率为10kHz。
- `MAIN_KEY2_SINGLE_TEST_MOTOR_ID = 2U`，KEY2当前选择代码中的 `motor2`，即物理电机3。
- `MAIN_KEY2_POSITION_TEST_ENABLE = 1U`、`MAIN_KEY2_SPEED_TEST_ENABLE = 1U`，当前KEY2走位置-速度-电流三环测试路径。
- `MAIN_AUTO_FOC_CALIB_ROUNDS = 2U`，上电自动校正两轮。

仍需优先验证：

1. 在触手4硬件上确认当前板级方向和电角度trim，不能沿用板3结论。
2. 用示波器验证异常电机三相PWM门极或相电压是否完整，排除缺相和板级连接问题。
3. 同时记录原始ADC和重构后电流，确认B相异常来自硬件采样还是软件重构。
4. 复核电角度offset校正公式的正负号，并与实际电角度定义统一。
5. 实机确认COAST后停机吸附是否消失，以及重新启动时是否平滑。
6. 三电机单独调通后再恢复三路同时位置控制，最后进行多触手CAN联调。

当前最高风险：

- 板级profile选择错误导致方向或电角度参数烧录到错误触手。
- 电机3 B相采样/重构异常尚未定位，可能继续造成发热、吸附和扭矩不匹配。
- COAST修改尚未完成全量编译和实机验证。
- 电角度校正公式仍有历史正负号疑点，不能仅依靠trim反复试错长期掩盖。

---

## 12. 2026-07-19 至 2026-09-29 项目后续开发记录

本章从第 11 章停止的位置继续记录。日期来源按以下优先级确定：Git 提交日期、工程快照和模型文件时间、串口与实验截图时间、开发材料生成时间。无法由单一文件确认到具体日期的连续调试工作使用日期范围，不人为补写不存在的精确时间。

### 12.1 2026-07-19 至 2026-07-31：多触手运行稳定性与控制链路收尾

现象：

- 单触手静止时 CAN 状态稳定，但运动后曾出现状态延迟、上位机显示掉线和自动停止；停止后节点又恢复在线。
- 四触手控制中，触手 4 的三路线缆方向一度不符合中心对称关系，出现三根线同时放松的情况。
- 上位机在未启动时切换模式或锁定参数后，界面显示的模式与 H7 实际运行模式可能不一致。
- W25Q64 频繁保存 ACTUAL 会占用主循环时间；只按固定周期保存又可能在停止后遗漏最后位置。

原因判断：

- G4 状态上报曾依赖 HAL SysTick；高频电机任务运行后，软件节拍和主循环负载变化会拉长状态帧间隔。
- H7 启动前的严格 READY 条件曾被错误复用于运行过程，把短暂状态延迟直接当作危险断连。
- 四触手安装方向、三电机收放线方向和协同关系变换分散在多个位置，触手 4 的方向修正不完整。
- 固定周期无条件写 Flash 会增加阻塞和擦写次数，且不能保证运动停止瞬间的最终位置一定入队。

处理方法：

- G4 状态上报改为固定硬件定时节拍分频，周期保持 50 ms，不再用 HAL SysTick 作为状态发送依据。
- H7 将“启动 READY”和“运行健康”分开：启动前严格检查在线、状态新鲜、无 FAULT 和恢复有效；运行中短暂波动仅告警，FAULT 与急停立即停止。
- 统一四触手工作模式、活动 mask 和方向表，触手安装差异只在固定映射层处理，不在 CAN、上位机和 G4 多处重复取反。
- W25 保存改为变化阈值触发和任务队列处理；运动停止后强制补记一次最终 ACTUAL，HOME 与 ACTUAL 保持同一快照语义。
- 上位机启动顺序固定为“下发模式 -> 查询并确认状态 -> MCTRL 1”，运行中不再用界面草稿代替 H7 实际状态。

当前结果：

- G4 改用固定定时节拍后，运动过程中的 CAN 卡顿明显下降；50 ms 状态周期满足当前监测需要。
- 单触手、双触手和四触手控制链路进入可演示状态，短暂 CAN 波动不再立即终止控制。
- 四触手方向仍需要逐触手使用小幅度命令做实物标定，不能仅依据软件符号推断最终收放线方向。

注意事项：

- 该阶段大量工作来自连续联调记录，没有为每次阈值调整单独提交 Git，因此日期采用范围表述。
- READY 放宽只针对短暂通信波动，不能放宽 FAULT、急停和实际位置失控保护。

---

### 12.2 2026-07-28 至 2026-08-06：单触手 ACT 方案与数据接口确定

目标：

- 使用触手 3 完成单触手示教学习演示。
- 通过 VL53L8CH 观察瓶子与触手状态，学习从初始位置到包裹瓶子的连续三电机轨迹。
- 保留每约 100 ms 重新感知和推理的能力，而不是只执行一次固定轨迹。

关键设计：

- 每个模型输入窗口使用连续 12 帧观测。
- 每帧 ToF 数据最终采用 18 个通道、8×8 区域，共 1152 个值；12 帧展平后为 13824 个值。
- 三电机 ACTUAL 作为独立输入，形状为 12×3，用于反映当前真实机械状态。
- 监督标签使用当前观测窗口之后的未来 10 帧三电机实际位置，形状为 10×3；不把当前帧命令错误地当作未来标签。
- 数据单位统一为 `q`，即 `1 q = 0.01 rad`，训练与 H7/G4 控制接口保持一致。

数据流：

```text
VL53L8CH 新帧 + 三电机 ACTUAL
-> H7 按同一采样时刻组帧
-> USART1 二进制采样帧
-> ACT 专用上位机校验并缓存
-> 一次完整抓取形成一个 Episode
-> 用户确认后保存，失败样本删除
-> 滑窗生成 12 帧输入和未来 10 帧标签
```

接口取舍：

- USART7 继续负责普通运动控制和命令反馈，USART1 专门发送 ACT 采样数据，避免控制文本与大数据帧互相干扰。
- 单个 Episode 先保存在 PC 内存中，结束后由用户选择保存或删除，不在每帧到达时生成大量零散文件。
- 二进制协议使用帧头、长度、样本序号和 CRC；PC 端遇到坏帧后重新搜索帧头，避免一次错位造成后续持续 CRC 错误。
- 采样帧只复制当前稳定缓冲区，H7 使用双缓冲隔离传感器更新和串口发送，避免发送过程中数据被覆盖。

当前结果：

- ACT 模型输入、标签、采样串口和 Episode 保存语义已经固定。
- 该阶段确定“模型输入不包含未来命令”，未来三电机位置只在训练阶段作为监督标签使用。

---

### 12.3 2026-08-06 至 2026-08-08：ACT 采集上位机与串口稳定性

现象：

- 初期采样只有 6 至 9 Hz，时间显示变化不均匀，CRC 错误有时会连续出现。
- 通过 USB 扩展坞连接时错误率明显上升；更换数据线或直接连接电脑后可达到约 11 Hz。
- 串口长帧发生一次错位后，旧解析器可能从错误位置继续解释，造成后续连续 CRC 失败。
- ToF 读取量、H7 成功组帧量和 PC 接收量不是同一个统计量，直接比较容易误判瓶颈。

处理方法：

- USART1 采样波特率最终使用 921600，避免过高速配置增加 USB 转串口和线缆误码。
- PC 解析器在 CRC 或长度异常后逐字节搜索下一处有效 magic，不把坏包之后的所有数据整体丢弃。
- 分别统计 ToF 新帧数、H7 打包数、UART 发送数、PC 收包数和 CRC 错误数，区分传感器帧率、发送拥塞与链路误码。
- VL53L8CH 工作频率与实际推理周期最终收敛到约 10 Hz；原始采集可在约 11 Hz 下记录，再在清洗阶段统一重采样。
- 上位机增加 Episode 开始、停止、保存、删除、帧数、时长、CRC 和序号跳变显示。

当前结果：

- 2026-08-08 保存 Git 节点 `4bfa32a Save ACT acquisition firmware baseline`。
- 采样链路能够持续保存完整 Episode，串口直连电脑时稳定性明显优于扩展坞。
- `ACT_PC_BUILD_WORK` 中形成采集上位机、协议、Episode 缓冲、测试和设计文档。

注意事项：

- CRC 错误只能说明传输帧不可信，不能直接说明 VL53 数据或模型错误。
- PC 显示帧率按成功通过协议校验的完整帧计算，不等于 I2C 测距启动次数。

---

### 12.4 2026-08-08 至 2026-08-09：训练接口、教师模型与嵌入式部署边界

现象：

- 早期训练中出现损失从一开始就很低、验证曲线震荡或后期发散，单看 best MAE 无法判断轨迹方向是否正确。
- 使用同一 Episode 的相邻窗口随机划分会让训练集和验证集高度相似，产生过于乐观的结果。
- ACT/Transformer 风格模型导出 ONNX 后，Cube.AI/Edge AI 对动态形状、注意力相关算子和部分图结构无法稳定转换。

处理方法：

- 数据按 Episode 划分训练、验证和测试集，防止相邻帧泄漏。
- 训练记录同时观察位置 MAE、三电机方向准确率、目标跳变量和平滑性，不用单一损失决定部署权重。
- 标签改为未来真实 ACTUAL，不再把慢速上位机命令直接作为动作真值。
- Transformer 保留为教师模型或离线基线；H7 部署路线改为固定输入长度、固定输出长度的轻量时序网络。
- 2026-08-09 在 CubeMX 重新生成前保存 `f1ef23e Save H7 ACT model before CubeMX generation` 和工程快照。

当前结论：

- Transformer 的时序建模思路可用于训练和蒸馏，但不继续通过堆叠转换补丁强行部署到 H7。
- 嵌入式模型必须优先满足固定形状、Cube.AI 可生成、内存可容纳和约 100 ms 内完成推理。

---

### 12.5 2026-08-09 至 2026-08-11：TCN/Delta-TCN 训练与 H7 双模型部署

模型方案：

- ToF 每帧先经过共享轻量 CNN 编码器提取空间特征。
- 三电机 ACTUAL 经过状态编码器后与 ToF 特征融合。
- 两层时间卷积网络处理 12 帧历史，动作头输出未来 10×3 三电机位置块。
- 后续版本学习相对变化并在模型内部结合 ACTUAL，导出图直接输出可使用的绝对 q 目标，避免 H7 再重复相加。

部署问题：

- CubeMX/X-CUBE-AI 重新生成曾覆盖 `app_x-cube-ai.c`，并把手势单输入模板错误用于 ACT 双输入模型。
- 手势 CNN 与 ACT TCN 若共用激活区或输入声明，会造成编译失败或运行时互相覆盖。
- 重新生成还会覆盖 I2C 速率、USART1 波特率、SD 卡未插入保护和部分用户调用入口。

处理方法：

- 手势 CNN 与 ACT 模型分别维护输入、输出和激活缓冲区，运行时只选择一套模型执行。
- ACT 模型保留两个输入：`[1,13824]` ToF 序列和 `[1,12,3]` 电机状态；输出为 `[1,10,3]`。
- 每次 CubeMX 生成后检查 AI 模板、Keil 文件列表、I2C 1 MHz、USART1 921600、SD 未插卡流程和用户代码区。
- 增加 `ACTMODEL` 串口诊断，单独验证模型初始化、输入填充、推理次数、返回码、耗时和三个输出 q。

验证结果：

- H7 连续推理返回 `result=0`，实测单次推理约 101 至 102 ms。
- 当前最终部署模型 `delta_tcn_scene6_epoch010` 约 692,059 个参数，权重约 692.42 KiB，激活区约 108.15 KiB，计算量约 8.54 MMACC/次。
- 手势识别模型 `gesture_openness_cnn.onnx` 与 ACT 模型可同时存在于 H7 工程，但不会同时运行。
- 2026-08-10 保存第一版双模型部署快照；2026-08-11 生成并验证 Delta-TCN 代码。

---

### 12.6 2026-08-11 至 2026-08-12：ACT 实机控制、动作块融合与震荡诊断

现象：

- 第一版模型有时直接跳向动作末端，未完整复现示教中的抬升、横向避线和下降包裹阶段。
- 每约 100 ms 重新推理时，相邻预测块对同一未来时刻的目标并不完全一致，电机可能在两个目标之间来回反转。
- 只取未来第 3 帧能够加快动作，但容易跳过中间阶段；只取最新第 1 帧又容易受预测噪声影响。
- 换场景或改变瓶子位置后震荡加重，说明训练分布和场景泛化仍有限。

处理方法：

- 每个动作块保存对应 `frame_seq`，根据当前序号计算 `frame_delta`，只融合对齐到同一物理时刻的预测。
- 多个旧动作块按时间衰减加权；普通丢一帧不清空历史，长时间间隔或序号异常才重置。
- 模型输出先经过时序融合，再按当前 ACTUAL 限制最大领先量，并按上一次已发送目标限制单周期步长。
- 增加 `ACTOSC?` 诊断，同时记录模型目标、已发送目标和实际位置的范围、回退量和反向次数，避免仅凭肉眼修改阈值。
- ACT 默认关闭，仅控制训练对应的触手 3，活动 mask 固定为 `0x04`；故障停止后不自动恢复运行。

当前结果：

- 时序融合降低了相邻目标跳变，能够继续保持每约 100 ms 根据最新环境重新推理。
- 模型预测、限幅后目标和物理 ACTUAL 的震荡来源可以分开观察。
- 该修改只能缓解滚动预测不一致，不能替代数据分布和模型训练；跨场景阶段漂移仍属于模型问题。

安全边界：

- `FAULT`、急停和已确认的控制超时仍需停止；安全停止原因通过 `MSTOP` 一次性返回。
- 震荡检测不能因单次 mask 消失立即清零长期计时，也不能因另一台电机稳定就降低正在震荡电机的融合等级；相关阈值需要通过 ACTOSC 连续数据验证。

---

### 12.7 2026-08-06 至 2026-08-28：数据集清洗、场景划分与比赛演示边界

数据整理结果：

- 原始数据共 221 条 Episode。
- 排除 2 条不同控制策略、3 条严重串口丢失和 2 条失败抓取，保留 214 条有效 Episode。
- 清洗后得到约 68,569 帧、约 114 min 数据，覆盖 6 种受控瓶子位置。
- 按 Episode 划分为训练 147 条、验证 30 条、测试 37 条，避免同一抓取过程的相邻窗口分散到不同集合。
- 原始采样约 11 Hz，训练版本统一到 10 Hz 时间轴；短冻结只在可确认连续性的范围内处理，严重丢失 Episode 直接排除。

训练调整：

- 对场景采样使用平方根权重，避免样本最多的位置完全主导训练，同时不过度放大少量场景。
- 使用受控噪声、轻度正则化和 stride 调整提高泛化性；保留无增强基线用于对照。
- 权重选择同时参考 MAE、方向准确率、平滑性和实机轨迹，不默认最后一个 epoch 最好。
- 最终比赛部署采用 `delta_tcn_scene6_epoch010.onnx`，不是早期 Transformer 或第一版 TCN 权重。

演示边界：

- 当前模型针对固定背景、受控瓶子和单触手 3 训练，能够证明感知、示教、训练、部署和在线控制链路成立。
- 换场景后仍可能出现跳步、卡在局部阶段或震荡，不能宣称任意物体、任意姿态和任意背景均可稳定抓取。
- 当前没有在统一条件下完成足够次数的重复抓取统计，因此 214/221 只能称为数据清洗保留率，不能称为模型成功率。

---

### 12.8 2026-08-28 至 2026-08-30：开发日志、比赛证据与软著材料整理

完成内容：

- 依据 Git 提交、工程日志、快照、串口截图、数据清洗报告、模型报告和实物照片，生成 iCAN 创新赛道完整开发日志。
- 开发日志使用具体日期和日期范围区分可直接确认与连续调试记录，不虚构会议发言和成功率。
- 文档明确 SpiRobs/OpenSpiRobs 的公开技术来源，团队原创工作集中于多触手系统集成、控制、感知、示教学习和整机联调。
- 文档如实说明 AI 工具用于方案讨论、代码辅助、问题排查、训练脚本和文档整理，最终实验、验证和决策由团队完成。
- 生成项目曲线、数据集场景分布、策略对比图和 30 页左右的 PDF 提交版本，并逐页进行版面检查。
- 整理嵌入式控制软件的软著申请表、程序鉴别材料和用户操作手册，统一软件名称、功能说明和源码范围。

当前结果：

- `iCAN开发日志` 目录保留 Word 与 PDF 正式版本。
- `soft_copyright_work` 目录保留源代码文档和用户手册的生成、预览及最终材料。
- 文档材料属于成果归档，不反向替代源码中的技术验证记录。

---

### 12.9 2026-09-24 至 2026-09-25：最终源码、模型与训练文件归档

目标：

- 从长期调试工作区中提取可运行、可说明和可继续维护的最终版本，避免把历史快照、编译缓存和临时工具当作正式源码。

归档内容：

- `G4_ThreeMotor_FOC`：STM32G474 三电机 FOC 最终工程。
- `H743VIT6_ACT主板`：STM32H743 感知、CAN、多触手控制和双模型部署工程。
- `gesture_openness_cnn.onnx`：手势开合 CNN 模型。
- `delta_tcn_scene6_epoch010.onnx`：单触手 ACT Delta-TCN 模型。
- `train_openness_cnn.py`、`train_tcn_distill.py`、`tcn_model.py` 及其完整 `training` 依赖。

处理方法：

- 保留 CubeMX `.ioc`、Keil `.uvprojx`、Core、Drivers、Middlewares、X-CUBE-AI 生成源码、最终模型和必要第三方许可。
- 排除 Keil 对象文件、HEX/AXF/MAP、日志、个人 UI 配置、Python 缓存、重复快照和 VL53 SUTD 桌面工具。
- 最终形成 `G4与H7双核仿生触手源码` 汇总目录，原始可运行工程保持不动。

---

### 12.10 2026-09-29：GitHub 发布工程建立与首次上传

本地发布目录：

```text
<repository-root>
```

仓库结构：

```text
firmware/
  g4-motor-controller/
  h7-main-controller/
pc/
  tentacle-controller/
  act-data-collector/
training/
  gesture-cnn/
  act-tcn/
models/
docs/
README.md
.gitignore
```

整理与验证：

- 将约 796 MB 的原始汇总内容筛选为约 50 MB 的发布源码，原始工程没有被移动或修改。
- 补齐 ACT 训练脚本依赖，避免只上传三个入口脚本而无法独立运行。
- 排除 SUTD、Keil 编译目录、缓存、日志、压缩包和个人配置。
- 对 34 个 Python 文件执行语法检查，全部通过。
- 检查发布目录，没有发现明显密钥字段和超过 20 MB 的单文件。
- 增加中文 README 和适用于 STM32/Keil/Python 的 `.gitignore`。

Git 记录：

- 本地初始提交：`8572e3e Initial project import`。
- 主分支：`main`，已设置跟踪 `origin/main`。
- 远程仓库：`https://github.com/Zchen-1902/stm32-intelligent-flexible-tentacle`。
- 首次推送成功，远程与本地工作区一致。

注意事项：

- GitHub 发布副本用于展示和协作，不替代 D 盘中的原始调试工程。
- 后续更新应先在真实工程中完成编译和实机验证，再同步到 E 盘发布仓库并提交。
- 当前仓库为公开仓库，提交前必须继续检查账号、Token、训练数据和比赛限制材料。

---

## 13. 截至 2026-09-29 的最终工程状态

### 13.1 已完成并形成文件证据

1. STM32G474 三电机 FOC、电流/速度/位置分层闭环及板级 profile。
2. STM32H743 的 VL53L8CH 感知、手势 CNN、ACT Delta-TCN、W25Q64、CAN/FDCAN 和双串口链路。
3. 单触手、双触手和四触手的上层控制与状态管理框架。
4. ACT 二进制采样协议、专用上位机、Episode 缓存与确认保存流程。
5. 221 条原始 Episode 的清洗、划分和 214 条有效数据集。
6. Transformer 教师/基线评估、TCN/Delta-TCN 训练、ONNX 导出和 Cube.AI 代码生成。
7. H7 双模型共存、ACT 约 101 至 102 ms 在线推理和串口诊断。
8. 动作块时序对齐融合、目标步长/领先限制及 model/sent/actual 三类震荡观测。
9. iCAN 开发日志、实验图表、软著源码文档和用户操作手册。
10. G4/H7/上位机/训练/模型的 GitHub 发布仓库。

### 13.2 已实现但仍需要继续量化

- ACT 在固定背景和受控瓶子位置下的重复抓取成功率。
- 不同瓶子位置、姿态、光照和背景变化下的跨场景泛化能力。
- 动作阶段完整性、平均完成时间、三电机目标跳变量和实际反向次数。
- 四触手同时运行时长、CAN 丢帧率、FAULT/STOP 响应时间和温升。
- W25Q64 写满回绕、多次断电和重新烧录后的恢复可靠性。
- 各 G4 板电机方向、电角度 offset、电流采样和 COAST 停机的一致性。

### 13.3 当前最高风险

- ACT 模型可能在训练分布外出现阶段跳跃、局部卡住或目标震荡。
- 一次推理约 101 至 102 ms，感知、推理和控制实际属于约 10 Hz 策略层，不能承担 G4 的高频实时闭环职责。
- 多触手安全依赖 G4 STOP 锁存、编码器新鲜度、H7 故障仲裁和上位机状态确认共同成立。
- 发布仓库不包含训练原始数据和全部历史快照，复现实验仍需保留本地数据归档。

### 13.4 后续建议顺序

1. 在独立目录重新克隆 GitHub 仓库，验证 H7/G4 工程入口和 Python 训练依赖。
2. 固定瓶子、背景、初始姿态和停止条件，完成不少于一组可统计的重复抓取实验。
3. 记录成功/失败、完成时间、最大温升、CAN 超时、目标反向次数和实际轨迹。
4. 根据失败类型决定补数据、重训模型或修改执行限制，不继续无依据叠加状态机。
5. 实机验证通过后再发布 HEX、上位机 EXE 和模型 Release，并在 README 标明硬件版本与烧录顺序。

---

## 14. 日志证据与日期说明

| 时间 | 主要证据 |
|---|---|
| 2026-04-09 至 2026-07-12 | Git 提交 `1202a47` 至 `d7d3930`、工程快照和前 11 章记录 |
| 2026-07-13 至 2026-07-18 | G4/H7 工程日志、串口截图和连续联调记录 |
| 2026-08-06 至 2026-08-08 | `ACT_PC_BUILD_WORK`、采样协议测试、Git `4bfa32a` |
| 2026-08-09 | Git `f1ef23e`、CubeMX 前工程快照和第一版 ONNX 文件 |
| 2026-08-09 至 2026-08-11 | TCN/Delta-TCN ONNX、Cube.AI 报告、双模型工程快照、ACTMODEL/ACTOSC 记录 |
| 2026-08-28 至 2026-08-30 | iCAN 开发日志 Word/PDF、图表和软著材料生成记录 |
| 2026-09-24 至 2026-09-25 | 最终双模型包、G4/H7 主板源码归档及汇总目录 |
| 2026-09-29 | GitHub 发布目录、提交 `8572e3e` 和远程推送结果 |

日期真实性说明：本日志能由 Git 或文件直接确认的节点使用具体日期；连续实验但缺少独立提交的工作使用日期范围。模型准确率、抓取成功率和可靠性数据只记录已经存在的统计，不使用训练损失或数据清洗比例替代实机成功率。

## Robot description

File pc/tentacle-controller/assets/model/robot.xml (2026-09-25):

<mujoco model="spiral_robot">
  <compiler angle="radian"/>
  <option gravity="0 0 0"/>
  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
  <worldbody>
    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
    <light pos="1 0.5 0.7" dir="-1 -0.5 -1" directional="true" castshadow="false" diffuse="1 1 1" specular="0.3 0.3 0.3"/>
    <body name="link1" pos="0 0 0.440708894">
      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
      <body name="link2" pos="0 0 0.043636849">
        <joint type="ball" stiffness="0.040000" damping="0.020000"/>
        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
      <body name="link3" pos="0 0 0.039786957">
        <joint type="ball" stiffness="0.033253" damping="0.018235"/>
        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
      <body name="link4" pos="0 0 0.036276724">
        <joint type="ball" stiffness="0.027645" damping="0.016627"/>
        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
      <body name="link5" pos="0 0 0.033076183">
        <joint type="ball" stiffness="0.022982" damping="0.015160"/>
        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
      <body name="link6" pos="0 0 0.030158013">
        <joint type="ball" stiffness="0.019106" damping="0.013822"/>
        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
      <body name="link7" pos="0 0 0.027497301">
        <joint type="ball" stiffness="0.015883" damping="0.012603"/>
        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
      <body name="link8" pos="0 0 0.025071331">
        <joint type="ball" stiffness="0.013204" damping="0.011491"/>
        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
      <body name="link9" pos="0 0 0.022859395">
        <joint type="ball" stiffness="0.010977" damping="0.010477"/>
        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
      <body name="link10" pos="0 0 0.020842608">
        <joint type="ball" stiffness="0.009126" damping="0.009553"/>
        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
      <body name="link11" pos="0 0 0.019003754">
        <joint type="ball" stiffness="0.007586" damping="0.008710"/>
        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
      <body name="link12" pos="0 0 0.017327134">
        <joint type="ball" stiffness="0.006307" damping="0.007942"/>
        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
      <body name="link13" pos="0 0 0.015798435">
        <joint type="ball" stiffness="0.005243" damping="0.007241"/>
        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
      <body name="link14" pos="0 0 0.014404607">
        <joint type="ball" stiffness="0.004359" damping="0.006602"/>
        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
      <body name="link15" pos="0 0 0.013133750">
        <joint type="ball" stiffness="0.003624" damping="0.006020"/>
        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
      <body name="link16" pos="0 0 0.011975015">
        <joint type="ball" stiffness="0.003012" damping="0.005488"/>
        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
      <body name="link17" pos="0 0 0.010918511">
        <joint type="ball" stiffness="0.002504" damping="0.005004"/>
        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
      <body name="link18" pos="0 0 0.009955217">
        <joint type="ball" stiffness="0.002082" damping="0.004563"/>
        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
      <body name="link19" pos="0 0 0.009076911">
        <joint type="ball" stiffness="0.001731" damping="0.004160"/>
        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
      <body name="link20" pos="0 0 0.008276094">
        <joint type="ball" stiffness="0.001439" damping="0.003793"/>
        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
      <body name="link21" pos="0 0 0.007545930">
        <joint type="ball" stiffness="0.001196" damping="0.003459"/>
        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
      <body name="link22" pos="0 0 0.006880185">
        <joint type="ball" stiffness="0.000994" damping="0.003153"/>
        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
      <body name="link23" pos="0 0 0.006273175">
        <joint type="ball" stiffness="0.000827" damping="0.002875"/>
        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
      <body name="link24" pos="0 0 0.005719720">
        <joint type="ball" stiffness="0.000687" damping="0.002622"/>
        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
      </body>
      </body>
      </body>
      </body>
      </body>
      </body>
      </body>
      </body>
      </body>
      </body>
      </body>
      </body>
      </body>
      </body>
      </body>
      </body>
      </body>
      </body>
      </body>
      </body>
      </body>
      </body>
      </body>
    </body>
  </worldbody>
  <tendon>
    <spatial name="tendon1" width="0.0007" frictionloss="0.1" rgba=".95 .3 .3 1" limited="true" range="0.176283557 1.101772234">
      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
    </spatial>
    <spatial name="tendon2" width="0.0007" frictionloss="0.1" rgba=".95 .3 .3 1" limited="true" range="0.176283557 1.101772234">
      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
    </spatial>
    <spatial name="tendon3" width="0.0007" frictionloss="0.1" rgba=".95 .3 .3 1" limited="true" range="0.176283557 1.101772234">
      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
    </spatial>
  </tendon>
  <actuator>
    <muscle name="act1" tendon="tendon1" ctrllimited="true" ctrlrange="0 1" force="5" lengthrange="0.176283557 1.101772234"/>
    <muscle name="act2" tendon="tendon2" ctrllimited="true" ctrlrange="0 1" force="5" lengthrange="0.176283557 1.101772234"/>
    <muscle name="act3" tendon="tendon3" ctrllimited="true" ctrlrange="0 1" force="5" lengthrange="0.176283557 1.101772234"/>
  </actuator>
</mujoco>

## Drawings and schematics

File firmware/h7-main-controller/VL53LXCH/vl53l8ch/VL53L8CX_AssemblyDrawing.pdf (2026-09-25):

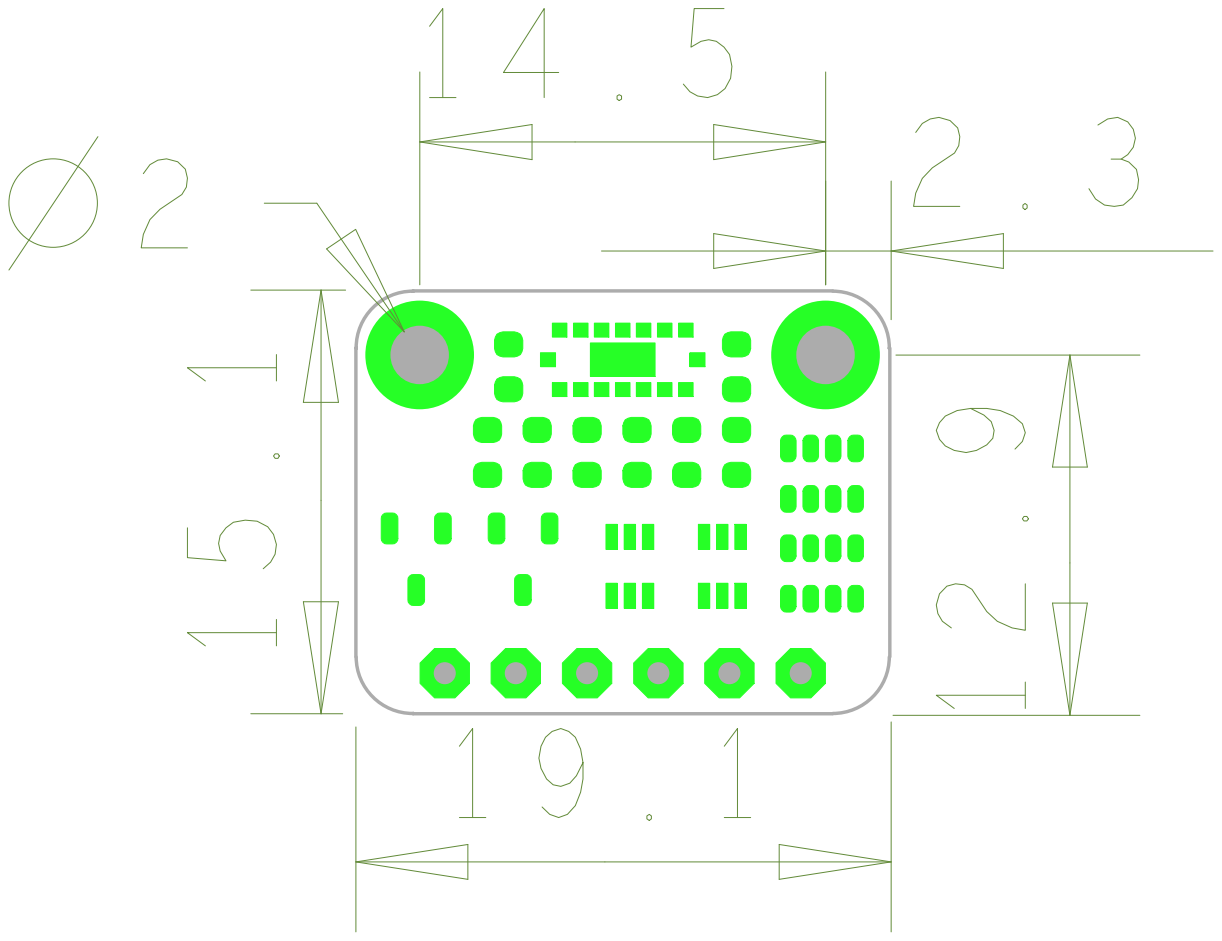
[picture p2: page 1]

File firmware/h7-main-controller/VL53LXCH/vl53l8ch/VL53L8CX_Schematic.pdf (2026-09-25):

47K C4

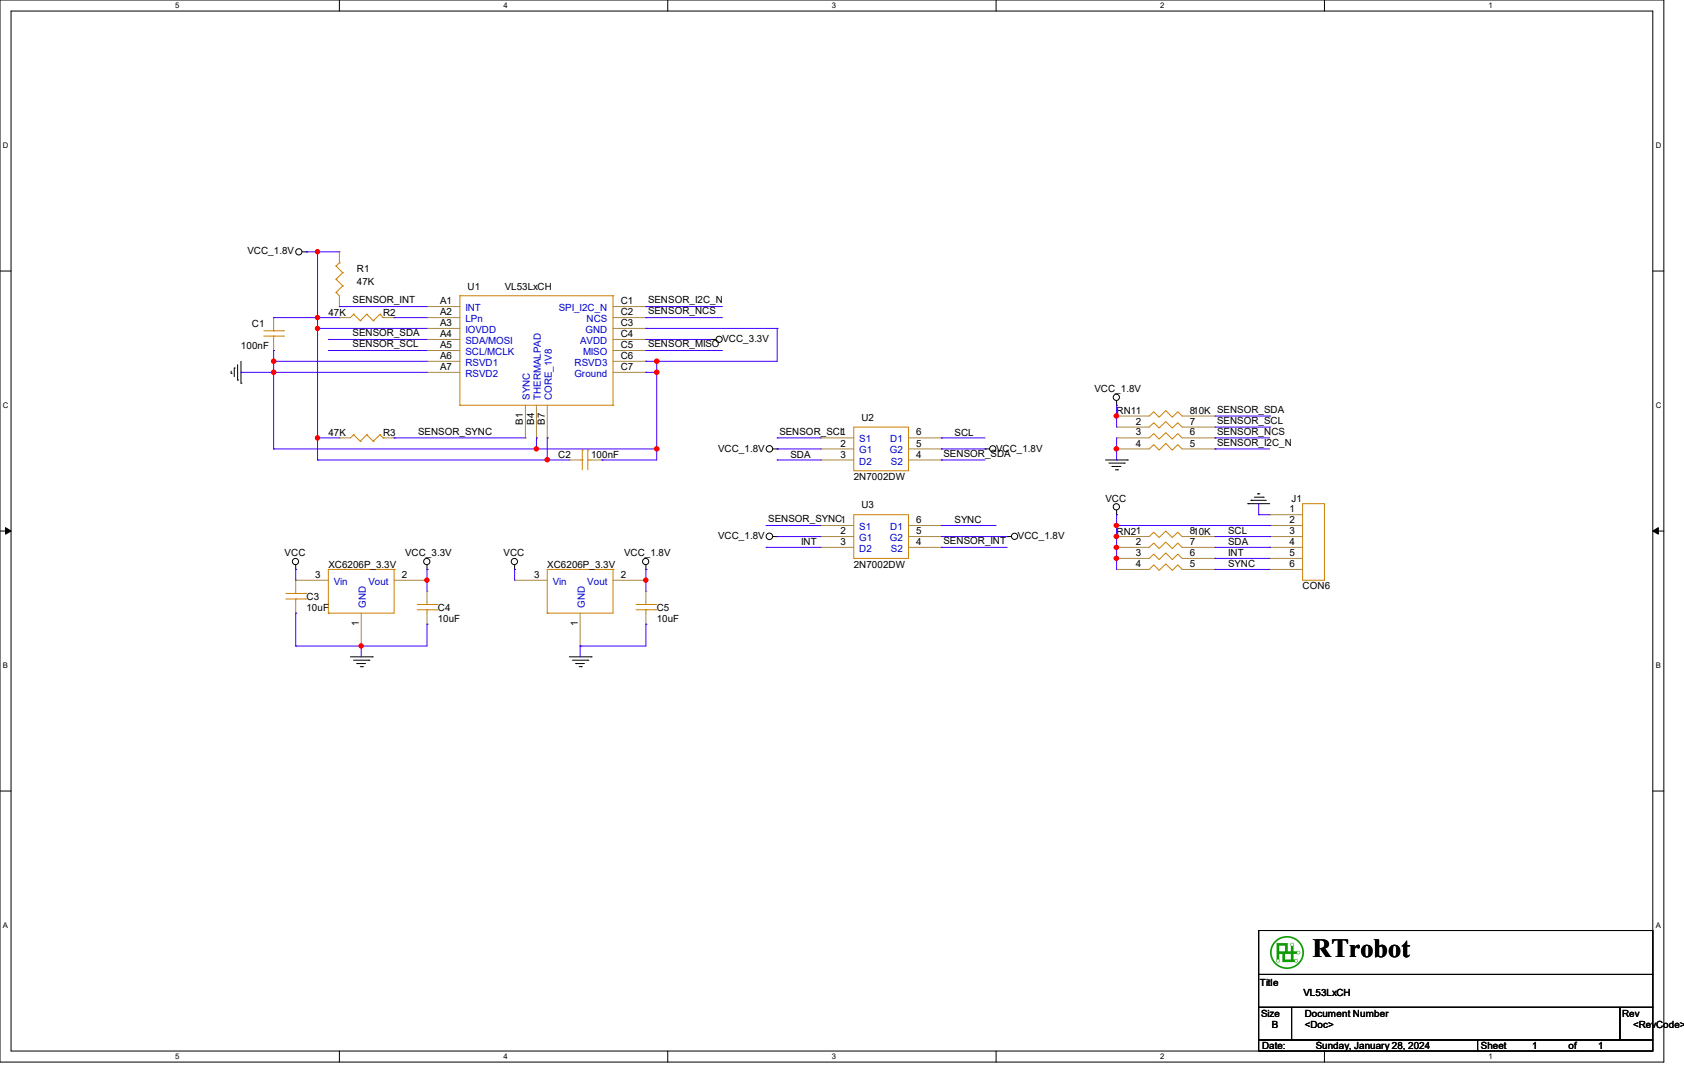
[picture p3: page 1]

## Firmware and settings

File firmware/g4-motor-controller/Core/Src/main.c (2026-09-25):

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
/* Includes ------------------------------------------------------------------*/
#include "main.h"
#include "adc.h"
#include "dma.h"
#include "fdcan.h"
#include "spi.h"
#include "tim.h"
#include "usart.h"
#include "gpio.h"

/* USER CODE BEGIN Includes */
#include "../Vofa_debug/Vofa_debug.h"
  #include "../timer_app/timer_app.h"
  #include "../adc_app/adc_app.h"
  #include "../spi_encoder/spi_encoder.h"
  #include "../drv8323S_drive/drv_drive.h"
  #include "../motor/motor_core.h"
  #include "../motor/Config.h"
  #include "../can_app/can_app.h"

/* USER CODE END Includes */

/* USER CODE BEGIN PD */
#define MAIN_FOC_ALIGN_VD_NORM        0.13f  // FOC电角度对齐d轴电压，首次真实测试建议0.01~0.02
#define MAIN_FOC_ROTATE_VQ_NORM       0.1f  // FOC开环旋转q轴电压，当前降低力度用于观察震动
#define MAIN_CURRENT_TEST_ID_REF_A    0.0f   // 电流环测试d轴电流目标，表贴电机第一版固定为0
#define MAIN_CURRENT_TEST_IQ_REF_A    0.2f   // 4010新电机相序验证用q轴电流目标，先低电流确认方向和采样相序
#define MAIN_SPEED_TEST_REF_RAD_S     20.0f  // KEY2速度环测试低速目标，单位rad/s
#define MAIN_SPEED_TEST_REF_HIGH_RAD_S 30.0f // KEY2速度环测试高速目标，单位rad/s
#define MAIN_POSITION_TEST_DELTA_RAD  5.0f  // KEY2位置环测试目标：当前位置基础上增加的机械角，单位rad
#define MAIN_KEY2_ADD_CURRENT_TEST_ENABLE 1U    // KEY2逐步追加电流环测试：motor0->+motor1->+motor2->全停
#define MAIN_KEY2_SINGLE_TEST_MOTOR_ID 2U       // KEY2单电机测试选择：0/1/2对应电机1/2/3
#define MAIN_KEY2_POSITION_TEST_ENABLE 1U    // KEY2测试模式：换4010后先关闭位置环，只验证电流环/相序
#define MAIN_KEY2_SPEED_TEST_ENABLE   1U     // KEY2测试模式：换4010后先关闭速度环，只验证单电流环
#define MAIN_AUTO_FOC_CALIB_ROUNDS    2U     // 上电后三电机FOC零偏自动顺序校正轮数
#define MAIN_ENCODER_DMA_ADC_DIV      2U     // 各电机ADC回调中编码器SPI DMA请求分频：10k/2=5kHz
#define MAIN_TIM7_ACTUAL_FREQ_HZ      ((uint32_t)SPEED_CALCU_FREQ * 10U) // TIM7实际中断频率，需与Config.h注释保持一致
#define MAIN_SPEED_LOOP_TIM7_DIV      (MAIN_TIM7_ACTUAL_FREQ_HZ / MOTOR_SPEED_LOOP_FREQ_HZ) // TIM7到速度环的分频
#define MAIN_POSITION_LOOP_TIM7_DIV   (MAIN_TIM7_ACTUAL_FREQ_HZ / MOTOR_POSITION_LOOP_FREQ_HZ) // TIM7到位置环的分频
#define MAIN_CAN_STATUS_FREQ_HZ       20U     // 运动期间G4状态帧上报频率
#define MAIN_CAN_STATUS_TIM7_DIV      (MAIN_TIM7_ACTUAL_FREQ_HZ / MAIN_CAN_STATUS_FREQ_HZ)

/* USER CODE END PD */


/* USER CODE BEGIN PV */
static uint32_t s_last_motor_control_cycles[MOTOR_COUNT] = {0U}; // 每个电机上一次实际控制执行时的DWT周期计数
static uint8_t s_motor_control_dt_valid[MOTOR_COUNT] = {0U};     // 每个电机控制dt首次运行标志
static uint32_t s_current_fast_loop_last_cycles[MOTOR_COUNT] = {0U}; // 每个电机ADC快环上一次进入时的DWT周期计数
static uint8_t s_current_fast_loop_dt_valid[MOTOR_COUNT] = {0U};     // 每个电机ADC快环真实dt首次运行标志
static uint8_t s_selected_motor_id = 2U;                         // 当前按键选中的电机编号，当前调试TIM20/DRV3链路
static uint8_t s_selected_motor_pwm_hw_started = 0U;             // 当前选中电机PWM硬件启动状态，1表示已调用Start
static uint8_t s_selected_motor_align_active = 0U;               // 当前选中电机是否处于FOC电角度校准对齐状态
static uint8_t s_selected_motor_rotate_active = 0U;              // 当前选中电机是否处于q轴开环旋转状态
static uint8_t s_selected_motor_current_active = 0U;             // 当前选中电机是否处于单电流环测试状态
static uint8_t s_key2_add_current_next_motor_index = 0U;         // KEY2逐步追加测试下一路待启动电机序号
static uint8_t s_key2_add_current_active_mask = 0U;              // KEY2逐步追加测试已启动电机位图，bit0/1/2对应motor0/1/2
static uint8_t s_key1_calib_seq_active = 0U;                     // KEY1三电机顺序校正是否进行中
static uint8_t s_key1_calib_seq_next_motor = 0U;                 // KEY1三电机顺序校正下一台电机序号
static uint8_t s_key1_calib_seq_started = 0U;                    // KEY1顺序校正是否已经成功启动过至少一台
static uint8_t s_key1_calib_seq_round = 0U;                      // 三电机顺序校正当前轮次
static uint8_t s_key2_speed_test_step = 1U;                      // KEY2速度环测试步进：0停机/待启动，1下次35，2下次20，3下次停机

/* USER CODE END PV */

void SystemClock_Config(void);
/* USER CODE BEGIN PFP */
static float Main_GetCurrentFastLoopDt(uint8_t motor_id); // 计算指定电机ADC快环真实dt
static uint8_t Main_StartNextMotorCurrentTest(void);      // KEY2逐步追加电流环测试启动下一路
static void Main_StopAllMotorCurrentTest(void);           // KEY2逐步追加电流环测试停止全部电机
static uint8_t Main_StartKey1CalibOne(uint8_t motor_id);   // KEY1顺序校正启动单台电机
static void Main_ServiceKey1CalibSequence(void);           // KEY1顺序校正推进器

/* USER CODE END PFP */

/**
  * @brief  The application entry point.
  * @retval int
  */
int main(void)
{

  /* MCU Configuration--------------------------------------------------------*/

  /* Reset of all peripherals, Initializes the Flash interface and the Systick. */
  HAL_Init();

  /* Configure the system clock */
  SystemClock_Config();

  /* Initialize all configured peripherals */
  MX_GPIO_Init();
  MX_DMA_Init();
  MX_ADC1_Init();
  MX_ADC3_Init();
  MX_ADC4_Init();
  MX_FDCAN1_Init();
  MX_TIM1_Init();
  MX_TIM8_Init();
  MX_TIM20_Init();
  MX_USART1_UART_Init();
  MX_USART2_UART_Init();
  MX_ADC2_Init();
  MX_SPI1_Init();
  MX_SPI3_Init();
  MX_TIM4_Init();
  MX_TIM6_Init();
  MX_TIM7_Init();
  MX_TIM3_Init();
  /* USER CODE BEGIN 2 */
  VOFA_Debug_Init();
  VOFA_Debug_SetTopic(VOFA_TOPIC_ENCODER);//默认查看电机2编码器主题，按KEY3可切换到FOC_TEST
  VOFA_Debug_SetPeriodMs(5U);             // VOFA发送周期5ms，约200Hz；USART1当前设置为115200
  if (DRV_Drive_Init() != HAL_OK)
  {
    Error_Handler();
  }
  Motor_Core_Init();                      // 初始化三电机软件对象和默认PID/校准参数
  Timer_App_Init();
  SPI_Encoder_Init();
  Motor_Core_ApplyEncoderOffsetConfig();  // 将Config.h中的编码器零点偏移同步到spi_encoder，避免motor_core重复扣零点
  if (CAN_App_Init() != HAL_OK)
  {
    Error_Handler();
  }
  Timer_App_Start();
  ADC_App_Init();
  (void)ADC_App_CalibrateMotorAdc();       // STM32 ADC内部自校准，必须在启动ADC DMA之前执行
  (void)ADC_App_StartMotorCurrentDma();
  if (Timer_App_StartMotorControlTimers() != HAL_OK)
  {
    Error_Handler();
  }
  (void)Motor_Core_CalibrateCurrentZero(); // 临时排查阶段：校准失败也继续运行，避免串口/VOFA被Error_Handler阻断
  (void)Motor_Core_TrimCurrentZeroResidual(); // CAL退出后再按真实采样链路微调零点残差

  s_key1_calib_seq_active = 1U;
  s_key1_calib_seq_next_motor = 0U;
  s_key1_calib_seq_started = 0U;
  s_key1_calib_seq_round = 0U;
  if (Main_StartKey1CalibOne(0U) == 0U)
  {
    s_key1_calib_seq_active = 0U;
    s_key1_calib_seq_started = 0U;
    s_key1_calib_seq_round = 0U;
  }

  /* USER CODE END 2 */

  /* Infinite loop */
  /* USER CODE BEGIN WHILE */
  while (1)
  {
    /* USER CODE END WHILE */

    /* USER CODE BEGIN 3 */
  //    uint8_t motor_id;

    VOFA_Debug_Task(); // VOFA内部按period_ms和DMA busy限速，放主循环可突破TIM4 5ms调用限制
    CAN_App_Task();
    Motor_Core_FocOffsetAutoCalibTask(); // KEY1启动后自动完成FOC零偏校准
    Main_ServiceKey1CalibSequence();      // KEY1三电机顺序校正推进器

      if (Timer_App_IsTaskReady(TIMER_APP_TASK_5MS) != 0U)
      {
        Timer_App_ClearTaskFlag(TIMER_APP_TASK_5MS);
      }

    if (Timer_App_IsTaskReady(TIMER_APP_TASK_SPEED_CALC) != 0U)
    {
      Timer_App_ClearTaskFlag(TIMER_APP_TASK_SPEED_CALC);
    }
/*
    for (motor_id = 0U; motor_id < Motor_Core_GetMotorCount(); motor_id++)
    {
      if (Timer_App_ConsumeMotorControlRequest(motor_id) != 0U)
      {
        uint32_t now_cycles;
        uint32_t delta_cycles;
        float control_dt_s;

          now_cycles = Timer_App_GetRuntimeCycles();
          if (s_motor_control_dt_valid[motor_id] == 0U)
          {
            control_dt_s = MOTOR_CURRENT_LOOP_DT_S;
            s_motor_control_dt_valid[motor_id] = 1U;
          }
          else
          {
            delta_cycles = now_cycles - s_last_motor_control_cycles[motor_id];
            control_dt_s = (float)delta_cycles / (float)SystemCoreClock;

            if (control_dt_s < MOTOR_CURRENT_LOOP_DT_MIN_S)
            {
              control_dt_s = MOTOR_CURRENT_LOOP_DT_MIN_S;
            }
            else if (control_dt_s > MOTOR_CURRENT_LOOP_DT_MAX_S)
            {
              control_dt_s = MOTOR_CURRENT_LOOP_DT_MAX_S;
            }
          }

        s_last_motor_control_cycles[motor_id] = now_cycles;

        if ((s_selected_motor_rotate_active != 0U) && (motor_id == s_selected_motor_id))
        {
          (void)Motor_Core_OutputFocQVoltage(s_selected_motor_id, MAIN_FOC_ROTATE_VQ_NORM);
          (void)Motor_Core_UpdateCurrentObserve(s_selected_motor_id); // 开环旋转时同步刷新电流观测量，供PHASE_CURRENT主题显示
        }
        else
        {
          (void)Motor_Core_TryUpdateFromPwmRequest(motor_id, control_dt_s);
        }
      }
    }
	*/
  }
  /* USER CODE END 3 */
}

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
/* USER CODE BEGIN 4 */
/**
  * @brief  计算指定电机ADC快环真实dt。
  * @param  motor_id: 电机编号，范围0~MOTOR_COUNT-1。
  * @retval 当前ADC快环dt，单位s。
  * @note   dt来源为DWT cycle差值，每个电机独立记录last cycle。
  *         第一次进入时使用默认MOTOR_CURRENT_LOOP_DT_S，后续做上下限保护。
  *         该dt表示两次ADC回调中实际进入快环入口的时间差，不等同于ADC硬件采样瞬间。
  */
static float Main_GetCurrentFastLoopDt(uint8_t motor_id)
{
  uint32_t now_cycles;
  uint32_t delta_cycles;
  float dt_s;

  if (motor_id >= MOTOR_COUNT)
  {
    return MOTOR_CURRENT_LOOP_DT_S;
  }

  now_cycles = Timer_App_GetRuntimeCycles();
  if (s_current_fast_loop_dt_valid[motor_id] == 0U)
  {
    dt_s = MOTOR_CURRENT_LOOP_DT_S;
    s_current_fast_loop_dt_valid[motor_id] = 1U;
  }
  else
  {
    delta_cycles = now_cycles - s_current_fast_loop_last_cycles[motor_id];
    dt_s = (float)delta_cycles / (float)SystemCoreClock;

    if (dt_s < MOTOR_CURRENT_LOOP_DT_MIN_S)
    {
      dt_s = MOTOR_CURRENT_LOOP_DT_MIN_S;
    }
    else if (dt_s > MOTOR_CURRENT_LOOP_DT_MAX_S)
    {
      dt_s = MOTOR_CURRENT_LOOP_DT_MAX_S;
    }
  }

  s_current_fast_loop_last_cycles[motor_id] = now_cycles;
  return dt_s;
}

/**
  * @brief  KEY2启动指定电机的位置-速度-电流三环测试。
  * @retval 1表示本次成功启动一路，0表示启动失败。
  * @note   目标为当前反馈位置增加MAIN_POSITION_TEST_DELTA_RAD，只启动选中电机。
  */
static uint8_t Main_StartNextMotorCurrentTest(void)
{
  uint8_t motor_id = MAIN_KEY2_SINGLE_TEST_MOTOR_ID;

  if (motor_id >= MOTOR_COUNT)
  {
    return 0U;
  }

  (void)Motor_Core_OutputNeutralPwm(motor_id);

  if (Motor_Core_IsPwmStartAllowed(motor_id) == 0U)
  {
    Main_StopAllMotorCurrentTest();
    return 0U;
  }

  if (Motor_Core_StartPwmOutput(motor_id) != HAL_OK)
  {
    Main_StopAllMotorCurrentTest();
    return 0U;
  }

  Motor_Core_SetCurrentRef(motor_id, MAIN_CURRENT_TEST_ID_REF_A, 0.0f);
  Motor_Core_SetSpeedRef(motor_id, 0.0f);
  Motor_Core_SetPositionRef(motor_id,
                            Motor_Core_GetPositionFeedbackRad(motor_id)
                            + ((motor_id == 0U) ? -MAIN_POSITION_TEST_DELTA_RAD
                                               : MAIN_POSITION_TEST_DELTA_RAD));
  Motor_Core_SetMode(motor_id, MOTOR_MODE_POSITION_SPEED_CURRENT);

  s_selected_motor_id = motor_id;
  s_selected_motor_pwm_hw_started = 1U;
  s_selected_motor_align_active = 0U;
  s_selected_motor_rotate_active = 0U;
  s_selected_motor_current_active = 1U;
  s_key2_add_current_active_mask = (uint8_t)(1U << motor_id);
  s_key2_speed_test_step = 0U;

  return 1U;
}

/**
  * @brief  停止KEY2逐步追加测试中的全部电机。
  * @retval None
  * @note   三路全部回到IDLE并关闭PWM输出，下一次KEY2重新从motor0开始。
  */
static void Main_StopAllMotorCurrentTest(void)
{
  uint8_t motor_id;

  for (motor_id = 0U; motor_id < MOTOR_COUNT; motor_id++)
  {
    Motor_Core_SetCurrentRef(motor_id, 0.0f, 0.0f);
    Motor_Core_SetSpeedRef(motor_id, 0.0f);
    Motor_Core_SetMode(motor_id, MOTOR_MODE_IDLE);
    (void)Motor_Core_StopPwmOutput(motor_id);
  }

  s_selected_motor_pwm_hw_started = 0U;
  s_selected_motor_align_active = 0U;
  s_selected_motor_rotate_active = 0U;
  s_selected_motor_current_active = 0U;
  s_key2_add_current_active_mask = 0U;
  s_key2_add_current_next_motor_index = 0U;
  s_key2_speed_test_step = 0U;
}

/**
  * @brief  KEY1顺序校正启动单台电机。
  * @param  motor_id: 电机编号。
  * @retval 1表示启动成功，0表示失败。
  * @note   仅用于顺序校正内部，不改KEY2路径。
  */
static uint8_t Main_StartKey1CalibOne(uint8_t motor_id)
{
  uint8_t pwm_ready;
  uint8_t key1_encoder_valid;
  uint8_t key1_start_allowed;
  uint8_t key1_start_called;
  uint8_t key1_start_ok;
  uint32_t key1_ccer_before;

  if (motor_id >= MOTOR_COUNT)
  {
    return 0U;
  }

  key1_encoder_valid = SPI_Encoder_Is_Valid((encoder_id_t)Motor_Core_GetBoundEncoderId(motor_id));
  key1_ccer_before = (motor_id == 0U) ? TIM1->CCER : ((motor_id == 1U) ? TIM8->CCER : TIM20->CCER);
  pwm_ready = 0U;
  key1_start_allowed = 0U;
  key1_start_called = 0U;
  key1_start_ok = 0U;

  (void)Motor_Core_OutputNeutralPwm(motor_id);

  key1_start_allowed = Motor_Core_IsPwmStartAllowed(motor_id);
  if (key1_start_allowed != 0U)
  {
    key1_start_called = 1U;
    if (Motor_Core_StartPwmOutput(motor_id) == HAL_OK)
    {
      key1_start_ok = 1U;
      pwm_ready = 1U;
    }
  }

  VOFA_Debug_RecordKey1PwmStart(key1_encoder_valid,
                                key1_start_allowed,
                                key1_start_called,
                                key1_start_ok,
                                pwm_ready,
                                key1_ccer_before,
                                (motor_id == 0U) ? TIM1->CCER : ((motor_id == 1U) ? TIM8->CCER : TIM20->CCER));

  if (pwm_ready == 0U)
  {
    return 0U;
  }

  s_selected_motor_id = motor_id;
  s_selected_motor_pwm_hw_started = 1U;
  s_selected_motor_align_active = 0U;
  s_selected_motor_rotate_active = 0U;
  s_selected_motor_current_active = 0U;
  s_key2_speed_test_step = 0U;

  Motor_Core_SetMode(motor_id, MOTOR_MODE_IDLE);
  Motor_Core_StartFocOffsetAutoCalib(motor_id, MAIN_FOC_ALIGN_VD_NORM);

  return (Motor_Core_IsFocOffsetAutoCalibBusy() != 0U) ? 1U : 0U;
}

/**
  * @brief  推进KEY1三电机顺序校正。
  * @retval None
  */
static void Main_ServiceKey1CalibSequence(void)
{
  if (s_key1_calib_seq_active == 0U)
  {
    return;
  }

  if (Motor_Core_IsFocOffsetAutoCalibBusy() != 0U)
  {
    s_key1_calib_seq_started = 1U;
    return;
  }

  if (s_key1_calib_seq_started == 0U)
  {
    s_key1_calib_seq_active = 0U;
    return;
  }

  s_key1_calib_seq_started = 0U;
  if (Motor_Core_GetFocOffsetAutoCalibResult() == 0U)
  {
    s_key1_calib_seq_active = 0U;
    return;
  }

  s_key1_calib_seq_next_motor++;
  if (s_key1_calib_seq_next_motor >= MOTOR_COUNT)
  {
    s_key1_calib_seq_round++;
    if (s_key1_calib_seq_round >= MAIN_AUTO_FOC_CALIB_ROUNDS)
    {
      s_key1_calib_seq_active = 0U;
      return;
    }

    s_key1_calib_seq_next_motor = 0U;
    if (Main_StartKey1CalibOne(0U) == 0U)
    {
      s_key1_calib_seq_active = 0U;
    }
    return;
  }

  if (Main_StartKey1CalibOne(s_key1_calib_seq_next_motor) == 0U)
  {
    s_key1_calib_seq_active = 0U;
  }
}

/**
  * @brief  将KEY1逐台校正序号清零。
  * @retval None
  */
/**
  * @brief  UART发送完成回调
  * @param  huart: 触发发送完成的串口句柄
  * @retval None
  * @note   该回调由HAL库在DMA发送完成后自动调用。
  *         这里将USART1发送完成事件转发给VOFA调试模块处理。
  */
void HAL_UART_TxCpltCallback(UART_HandleTypeDef *huart)
{
  VOFA_Debug_TxCpltCallback(huart);
}

/**
  * @brief  UART错误回调
  * @param  huart: 发生错误的串口句柄
  * @retval None
  * @note   该回调由HAL库在串口或DMA发送异常时自动调用。
  *         这里将USART1错误事件转发给VOFA调试模块处理。
  */
void HAL_UART_ErrorCallback(UART_HandleTypeDef *huart)
{
  VOFA_Debug_ErrorCallback(huart);
}

/**
  * @brief  TIM周期到达回调
  * @param  htim: 触发周期回调的定时器句柄
  * @retval None
  * @note   当前用于把TIM4 5ms基础节拍转发给timer_app，由timer_app产生软件任务标志。
  */
void HAL_TIM_PeriodElapsedCallback(TIM_HandleTypeDef *htim)
{
  Timer_App_PeriodElapsedCallback(htim);

  if ((htim != NULL) && (htim->Instance == TIM7))
  {
    static uint16_t speed_loop_div[MOTOR_COUNT] = {0U};
    static uint16_t position_loop_div[MOTOR_COUNT] = {0U};
    static uint16_t can_status_div = 0U;
    static uint32_t last_speed_cycles[MOTOR_COUNT] = {0U};
    static uint8_t speed_dt_valid[MOTOR_COUNT] = {0U};
    uint32_t now_cycles;
    uint8_t motor_id;
    encoder_id_t encoder_id;
    HAL_StatusTypeDef speed_status;
    float speed_dt_s;
    uint8_t active_motor_mask;

    active_motor_mask = (uint8_t)(s_key2_add_current_active_mask | CAN_App_GetActiveMotorMask());
    if (active_motor_mask == 0U)
    {
      return;
    }

    for (motor_id = 0U; motor_id < MOTOR_COUNT; motor_id++)
    {
      if ((active_motor_mask & (1U << motor_id)) == 0U)
      {
        continue;
      }

      position_loop_div[motor_id]++;
      if (position_loop_div[motor_id] >= MAIN_POSITION_LOOP_TIM7_DIV)
      {
        position_loop_div[motor_id] = 0U;
        (void)Motor_Core_RunPositionOuterLoopFromTim7(motor_id, MOTOR_POSITION_LOOP_DT_S);
      }

      speed_loop_div[motor_id]++;
      if (speed_loop_div[motor_id] >= MAIN_SPEED_LOOP_TIM7_DIV)
      {
        speed_loop_div[motor_id] = 0U;

        /*
         * TIM7分频后作为速度外环节拍：
         * 1. 只根据已有编码器角度缓存计算速度，不启动SPI传输；
         * 2. 速度环只更新iq_ref，不跑电流环、不跑FOC、不写CCR；
         * 3. 电流快环仍由各自ADC DMA完成回调触发。
         */
        now_cycles = Timer_App_GetRuntimeCycles();
        if (speed_dt_valid[motor_id] == 0U)
        {
          speed_dt_s = MOTOR_SPEED_LOOP_DT_S;
          speed_dt_valid[motor_id] = 1U;
        }
        else
        {
          speed_dt_s = (float)(now_cycles - last_speed_cycles[motor_id]) / (float)SystemCoreClock;
          if (speed_dt_s < (MOTOR_SPEED_LOOP_DT_S * 0.2f))
          {
            speed_dt_s = MOTOR_SPEED_LOOP_DT_S * 0.2f;
          }
          else if (speed_dt_s > (MOTOR_SPEED_LOOP_DT_S * 5.0f))
          {
            speed_dt_s = MOTOR_SPEED_LOOP_DT_S * 5.0f;
          }
        }
        last_speed_cycles[motor_id] = now_cycles;

        encoder_id = (encoder_id_t)Motor_Core_GetBoundEncoderId(motor_id);
        speed_status = SPI_Encoder_Update_Speed_By_Cache(encoder_id, speed_dt_s);

        if (speed_status == HAL_OK)
        {
          (void)Motor_Core_RunSpeedOuterLoopFromTim7(motor_id, speed_dt_s);
        }
      }
    }

    /*
     * 状态上报使用TIM7固定分频，不依赖最低优先级的HAL Tick。
     * 放在三电机循环外，避免某一路位置环提前返回后停止上报。
     */
    can_status_div++;
    if (can_status_div >= MAIN_CAN_STATUS_TIM7_DIV)
    {
      can_status_div = 0U;
      CAN_App_RequestStatusTx();
    }
  }
}

/**
  * @brief  SPI DMA收发完成回调
  * @param  hspi: 触发DMA完成的SPI句柄
  * @retval None
  * @note   当前用于把SPI3编码器DMA完成事件转发给spi_encoder模块。
  */
void HAL_SPI_TxRxCpltCallback(SPI_HandleTypeDef *hspi)
{
  SPI_Encoder_TxRxCpltCallback(hspi);
}

/**
  * @brief  SPI错误回调
  * @param  hspi: 触发错误的SPI句柄
  * @retval None
  * @note   当前用于把SPI3编码器DMA错误事件转发给spi_encoder模块，
  *         防止编码器DMA busy状态卡死。
  */
void HAL_SPI_ErrorCallback(SPI_HandleTypeDef *hspi)
{
  SPI_Encoder_ErrorCallback(hspi);
}

/**
  * @brief  ADC转换完成回调
  * @param  hadc: 触发转换完成回调的ADC句柄
  * @retval None
  * @note   当前用于把ADC DMA完成事件转发给adc_app，由adc_app维护raw更新标志。
  */
void HAL_ADC_ConvCpltCallback(ADC_HandleTypeDef *hadc)
{
  uint8_t active_motor_mask;

  ADC_App_ConvCpltCallback(hadc);

  if (hadc == NULL)
  {
    return;
  }

  active_motor_mask = (uint8_t)(s_key2_add_current_active_mask | CAN_App_GetActiveMotorMask());

  if (hadc->Instance == ADC4)
  {
    static uint8_t encoder1_dma_div = 0U;

    if ((active_motor_mask & (1U << 0U)) != 0U)
    {
      (void)Motor_Core_RunCurrentFastLoopDirectFromAdc(0U, Main_GetCurrentFastLoopDt(0U));
    }

    if ((s_selected_motor_id == 0U) && (s_selected_motor_current_active == 0U))
    {
      (void)Motor_Core_UpdateCurrentObserve(0U);
    }

    encoder1_dma_div++;
    if (encoder1_dma_div >= MAIN_ENCODER_DMA_ADC_DIV)
    {
      encoder1_dma_div = 0U;
      (void)SPI_Encoder_Request_Update_DMA(encoder_id_1, Timer_App_GetRuntimeCycles());
    }
    (void)SPI_Encoder_ServicePendingOnce();
  }
  else if (hadc->Instance == ADC3)
  {
    static uint8_t encoder2_dma_div = 0U;

    if ((active_motor_mask & (1U << 1U)) != 0U)
    {
      (void)Motor_Core_RunCurrentFastLoopDirectFromAdc(1U, Main_GetCurrentFastLoopDt(1U));
    }

    if ((s_selected_motor_id == 1U) && (s_selected_motor_current_active == 0U))
    {
      (void)Motor_Core_UpdateCurrentObserve(1U);
    }

    encoder2_dma_div++;
    if (encoder2_dma_div >= MAIN_ENCODER_DMA_ADC_DIV)
    {
      encoder2_dma_div = 0U;
      (void)SPI_Encoder_Request_Update_DMA(encoder_id_2, Timer_App_GetRuntimeCycles());
    }
    (void)SPI_Encoder_ServicePendingOnce();
  }
  else if (hadc->Instance == ADC1)
  {
    static uint8_t encoder3_dma_div = 0U;

    if ((active_motor_mask & (1U << 2U)) != 0U)
    {
      (void)Motor_Core_RunCurrentFastLoopDirectFromAdc(2U, Main_GetCurrentFastLoopDt(2U));
    }

    if ((s_selected_motor_id == 2U) && (s_selected_motor_current_active == 0U))
    {
      (void)Motor_Core_UpdateCurrentObserve(2U);
    }

    encoder3_dma_div++;
    if (encoder3_dma_div >= MAIN_ENCODER_DMA_ADC_DIV)
    {
      encoder3_dma_div = 0U;
      (void)SPI_Encoder_Request_Update_DMA(encoder_id_3, Timer_App_GetRuntimeCycles());
    }
    (void)SPI_Encoder_ServicePendingOnce();
  }
}

/**
  * @brief  ADC错误回调
  * @param  hadc: 触发错误回调的ADC句柄
  * @retval None
  * @note   当前用于把ADC错误事件转发给adc_app，第一版adc_app只保留入口，不做复杂处理。
  */
void HAL_ADC_ErrorCallback(ADC_HandleTypeDef *hadc)
{
  ADC_App_ErrorCallback(hadc);
}
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

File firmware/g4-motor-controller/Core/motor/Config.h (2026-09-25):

#ifndef __CONFIG_H
#define __CONFIG_H

/*
 * 板级参数选择：
 * 1~4分别对应触手1~4驱动板。
 * 每个配置只区分CAN节点号、闭环反馈方向和FOC电角度微调。
 * PID、编码器、机械传动和保护参数由四块板共同使用。
 */
#ifndef G4_BOARD_PROFILE_ID
#define G4_BOARD_PROFILE_ID 4U
#endif


/*****************************************无刷电机参数*****************************************

电机名称：BM3520H
额定电压 (Nominal voltage)		   7.4-36 V
空载电流 (No-load current)		   0.3 A
额定扭矩 (Nominal torque)		   0.1 N.M
最大转速 (Max speed)	    	   3500 rpm
堵转扭矩 (Stall torque)	    	   0.1 N.M
堵转电流 (Stall current)		   3.3 A
相间电阻 (Interphase resistance)    7.8Ω
相间电感 (Interphase inductance)    3.6mH
转速常数 (Speed constant)	       125 rpm/v
极对数 (Number of pole pairs)	   7
工作温度范围 (Working temperature)  -40~100 ℃
最高退磁温度 (Max demagnetize temperature)  150 ℃   


**************************************************************************************************/

//******************************************电机参数*******************************************/
#define MOTOR_COUNT                      3           // 电机数量
#define PHASE_COUNT_PER_MOTOR            3           // 每个电机3相
#define TOTAL_PHASE_CURRENT_CHANNELS     9           // 总共9路相电流采样

#define POLE_PAIRS                      11              // 4010电机24N22P，22极对应11极对数

#define MOTOR_KV_RPM_PER_V              45.0f           // 4010按Kt=0.21N.m/A估算Kv约45rpm/V，后续以实测修正

#define MOTOR_VOLTAGE_NOMINAL_V         24.0f           // 标称工作电压
#define MOTOR_VOLTAGE_MAX_V             24.0f           // 4010电机电压范围12~24V
#define MOTOR_SPEED_RATED_RPM           800.0f          // 4010初期保守速度估算，后续以实测空载速度修正
#define MOTOR_SPEED_MAX_RPM             1100.0f         // 4010按24V和Kv估算的最大机械转速上限

#define MOTOR_CURRENT_RATED_A           1.0f            // 4010初期保守额定电流
#define MOTOR_CURRENT_MAX_A             1.5f            // 4010初期验证最大工作电流
#define MOTOR_CURRENT_PEAK_A            2.0f            // 4010参数表最大瞬间电流2A

#define MOTOR_KT_NM_PER_A               0.21f           // 4010转矩常数，单位N.m/A，用于反电动势磁链估算
#define MOTOR_FLUX_WB                   (MOTOR_KT_NM_PER_A / (1.5f * (float)POLE_PAIRS)) // 永磁磁链估算值，单位Wb
#define MOTOR_BEMF_FF_ENABLE            1U              // q轴反电动势前馈使能：先只补vq，不做Ld/Lq交叉解耦
#define MOTOR_BEMF_FF_GAIN              -0.63f           // 反电动势前馈增益，初期只补20%，方向不对可改成负值验证
#define MOTOR_BEMF_FF_LIMIT_NORM        0.20f           // 反电动势前馈归一化限幅，避免速度估计异常时直接推飞
#define MOTOR_BEMF_FF_SPEED_MIN_RAD_S   2.0f            // 低速时不补偿，避免静止噪声引入vq偏置


//******************************************ADC参数*******************************************/
#define ADC_VREF_V                     3.3f            // ADC参考电压
#define ADC_RESOLUTION_BITS            12              // ADC分辨率
#define ADC_MAX_COUNT                  4095.0f         // 12bit ADC最大计数值

#define CURRENT_SHUNT_OHM              0.01f           // 电流采样分流电阻
#define CURRENT_AMP_GAIN               20.0f           // 电流采样放大倍数
#define CURRENT_ADC_MID_V              1.65f           // 双向电流采样中点偏置电压

#define CURRENT_ZERO_CALIB_SAMPLES     500             // 上电零点校准采样次数
#define CURRENT_ZERO_VALID_RANGE_COUNT_F 100.0f        // 零点漂移允许范围（浮点计数阈值）

#define M1_IA_ZERO_CORRECT_V            0.000f      // 电机1 A相零电流校正电压
#define M1_IB_ZERO_CORRECT_V            0.000f      // 电机1 B相零电流校正电压
#define M1_IC_ZERO_CORRECT_V            0.000f      // 电机1 C相零电流校正电压

#define M2_IA_ZERO_CORRECT_V            0.000f      // 电机2 A相零电流校正电压
#define M2_IB_ZERO_CORRECT_V            0.000f      // 电机2 B相零电流校正电压
#define M2_IC_ZERO_CORRECT_V            0.000f      // 电机2 C相零电流校正电压

#define M3_IA_ZERO_CORRECT_V            0.000f      // 电机3 A相零电流校正电压
#define M3_IB_ZERO_CORRECT_V            0.000f      // 电机3 B相零电流校正电压
#define M3_IC_ZERO_CORRECT_V            0.000f      // 电机3 C相零电流校正电压

//******************************************电流采样相序映射*******************************************/
// 说明：这里配置“FOC算法U/V/W三相电流”分别使用ADC采样Rank A/B/C中的哪一路。
// 默认ABC表示：ia=ADC_A，ib=ADC_B，ic=ADC_C。
// 若电流环中iq跟踪异常、id明显串入，可尝试ACB/BAC/BCA/CAB/CBA。
#define MOTOR_CURRENT_U_ADC_PHASE        ADC_APP_PHASE_A // FOC U相电流使用的ADC采样相
#define MOTOR_CURRENT_V_ADC_PHASE        ADC_APP_PHASE_B // FOC V相电流使用的ADC采样相
#define MOTOR_CURRENT_W_ADC_PHASE        ADC_APP_PHASE_C // FOC W相电流使用的ADC采样相

#define IDX_M1_IA                        0           // 电机1 A相电流索引
#define IDX_M1_IB                        1           // 电机1 B相电流索引
#define IDX_M1_IC                        2           // 电机1 C相电流索引

#define IDX_M2_IA                        3           // 电机2 A相电流索引
#define IDX_M2_IB                        4           // 电机2 B相电流索引
#define IDX_M2_IC                        5           // 电机2 C相电流索引

#define IDX_M3_IA                        6           // 电机3 A相电流索引
#define IDX_M3_IB                        7           // 电机3 B相电流索引
#define IDX_M3_IC                        8           // 电机3 C相电流索引
//******************************************数学基础宏定义*******************************************/
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

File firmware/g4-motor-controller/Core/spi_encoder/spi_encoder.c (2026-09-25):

#include "spi_encoder.h"
#include <math.h>
#include <string.h>
#include "../timer_app/timer_app.h"

/************************************************
* MT6816 SPI 编码器驱动
* 功能：读取机械角、设置零点、计算多圈角度和机械角速度
************************************************ */

/****************************************************** 内部宏定义 ************************************************************************** */
#define ENCODER_CYCLE_RAD      (2.0f * M_PI_F) // 机械角单圈周期，单位 rad
#define ENCODER_SPI_BURST_READ_ENABLE 1U     // 1=手册burst read：TX 83 00 00；0=原两次CS分开读0x03/0x04
#if (ENCODER_SPI_BURST_READ_ENABLE != 0U)
#define ENCODER_FRAME_LEN      3U            // MT6816 burst read：TX 83 00 00，RX xx H L/status
#else
#define ENCODER_FRAME_LEN      2U            // MT6816 8bit SPI单寄存器读帧：TX CMD 00，RX xx DATA
#endif
#define ENCODER_RX_CACHE_LEN   4U            // 组合两次读寄存器结果：rx0 H帧dummy，rx1 H，rx2 L帧dummy，rx3 L/status
#define ENCODER_ANGLE_H_CMD    0x83U         // 读0x03：Angle[13:6]
#define ENCODER_ANGLE_L_CMD    0x84U         // 读0x04：Angle[5:0] + No_Mag + Parity
#define ENCODER_FRAME_MASK     0x3FFFU       // MT6816 角度数据按 14bit 处理
#define ENCODER_NO_MAG_MASK    0x02U         // MT6816 0x04[1]，磁场不足报警位
#define ENCODER_PARITY_MASK    0x01U         // MT6816 0x04[0]，偶校验位
#define ENCODER_CS_SETUP_DELAY_LOOP  20U      // CS拉低到首个SCK前的软件延时，约数百ns~1us量级
#define ENCODER_CS_HOLD_DELAY_LOOP   10U      // SPI空闲到CS拉高前的软件延时，避免截断帧尾
#define ENCODER_SPI_IDLE_TIMEOUT     1000U    // 等待SPI不忙的最大轮询次数，防止异常时卡死
#define ENCODER1_RAW_JUMP_REJECT_COUNT 4096U  // encoder1单次raw跳变拒绝阈值，14bit整圈的1/4；用于丢弃偶发0值/毛刺帧
#define ENCODER1_RAW_JUMP_PREDICT_MAX 3U      // encoder1连续毛刺帧最多预测次数，超过后判无效避免长期盲跑

/****************************************************** 编码器数据 ************************************************************************** */
spi_encoder_t spi_encoder[ENCODER_NUM] = {0};   // 3 路编码器的软件数据缓存

/****************************************************** 编码器配置 ************************************************************************** */
static const int8_t s_encoder_dir[ENCODER_NUM] =
{
    ENCODER_DIR_M1,
    ENCODER_DIR_M2,
    ENCODER_DIR_M3,
};

/****************************************************** 内部变量 **************************************************************************** */
// MT6816 SPI发送缓存：burst模式TX 83 00 00；分开读模式TX CMD 00
static uint8_t s_spi_tx_buf[ENCODER_FRAME_LEN] = {ENCODER_ANGLE_H_CMD, 0x00U};
static uint8_t s_spi_rx_buf[ENCODER_RX_CACHE_LEN] = {0U};

static uint8_t s_spi_dma_rx_buf[ENCODER_NUM][ENCODER_RX_CACHE_LEN] = {0U}; // 三路编码器DMA接收缓存
static uint16_t s_spi_dma_raw[ENCODER_NUM] = {0U};                      // 三路编码器DMA解析后的raw缓存
static uint8_t s_spi_dma_raw_valid[ENCODER_NUM] = {0U};                 // 三路raw缓存有效标志

static volatile uint8_t s_spi_dma_busy = 0U;                            // SPI3编码器DMA忙标志
static volatile uint8_t s_spi_dma_index = 0U;                           // 当前正在读取的编码器序号
static volatile uint8_t s_spi_dma_read_low_reg = 0U;                    // 当前DMA是否已完成高字节、准备/正在读低字节
static volatile uint8_t s_spi_dma_single_mode = 0U;                     // 单路DMA模式标志，1表示本轮只读取一个编码器
static volatile uint8_t s_spi_dma_pending_service_active = 0U;          // 当前单路DMA是否来自pending调度，避免污染旧all-DMA时间基准
static volatile uint8_t s_spi_dma_update_done = 0U;                     // DMA读取并更新完成标志，单路/三路DMA完成后都会置位
static volatile uint32_t s_spi_dma_missed_count = 0U;                   // DMA忙时被跳过的启动次数
static volatile uint8_t s_spi_dma_pending_mask = 0U;                    // 单路DMA请求pending位图，bit0/1/2对应三路编码器
static volatile uint8_t s_spi_dma_next_pending_index = 0U;              // pending轮询起点，避免总是优先同一路
static volatile uint32_t s_spi_dma_pending_cycles[ENCODER_NUM] = {0U};  // 每路最近一次请求时间戳，单位DWT cycle
static volatile uint32_t s_spi_dma_pending_overwrite_count[ENCODER_NUM] = {0U}; // pending未消费时被新请求覆盖的次数

static uint32_t s_spi_dma_current_start_us = 0U;                        // 本轮DMA读取启动时间
static uint32_t s_spi_dma_last_success_start_us = 0U;                   // 上一轮成功启动时间
static uint8_t s_spi_dma_has_last_success_time = 0U;                    // 是否已经有上一轮成功采样时间
static float s_spi_dma_dt = 0.0f;                                       // 本轮速度计算使用的时间间隔，单位s
static uint8_t s_speed_calc_initialized[ENCODER_NUM] = {0U};            // TIM7速度低通是否已有基准值
static uint8_t s_encoder1_raw_jump_predict_count = 0U;                  // encoder1 raw毛刺后使用速度预测补帧的连续次数

/****************************************************** 内部函数声明 *********************************************************************** */
static uint8_t SPI_Encoder_Id_Is_Valid(encoder_id_t id);             // 判断编码器编号是否有效
static HAL_StatusTypeDef SPI_Encoder_Parse_Raw_Frame(encoder_id_t id, const uint8_t *rx_buf, uint16_t *raw); // 解析MT6816三字节返回帧
static HAL_StatusTypeDef SPI_Encoder_Update_By_Raw(encoder_id_t id, uint16_t raw_now, float dt); // 使用已缓存raw更新角度和速度
static HAL_StatusTypeDef SPI_Encoder_Start_DMA_By_Index(uint8_t index); // 按序号启动一路编码器DMA读取
static HAL_StatusTypeDef SPI_Encoder_Start_DMA_Burst_Frame(uint8_t index); // 启动一次0x03/0x04 burst read DMA读取
static HAL_StatusTypeDef SPI_Encoder_Start_DMA_Read_Reg(uint8_t index, uint8_t cmd, uint8_t *rx_buf); // 启动一次寄存器DMA读取
static void SPI_Encoder_Update_All_By_DMA_Raw(float dt);              // 使用三路DMA raw缓存统一更新角度和速度
static uint8_t SPI_Encoder_Check_Parity(uint8_t angle_high, uint8_t angle_low_status); // 检查MT6816角度帧偶校验
static float SPI_Encoder_Apply_Direction(encoder_id_t id, float angle_rad); // 按编码器方向和零点偏移换算单圈角
static void SPI_Encoder_Update_Turn_Count(encoder_id_t id, float angle_last, float angle_now, float diff); // 更新显式多圈计数
static GPIO_TypeDef *SPI_Encoder_Get_CS_Port(encoder_id_t id);       // 获取对应编码器的片选端口
static void SPI_Encoder_DelayLoop(uint32_t loop);                    // 短软件延时，用于CS建立/保持时间
static void SPI_Encoder_CS_SetupDelay(void);                         // CS拉低后的建立时间
static void SPI_Encoder_WaitSpiIdle(void);                           // 等待SPI3发送移位完全结束
static uint16_t SPI_Encoder_Get_CS_Pin(encoder_id_t id);             // 获取对应编码器的片选引脚
static void SPI_Encoder_CS_Select(encoder_id_t id);                  // 拉低对应编码器片选
static void SPI_Encoder_CS_Release(encoder_id_t id);                 // 释放对应编码器片选
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

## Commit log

2026-09-25 Initial project import
    [baselink.stl, robot.xml]
2026-10-06 Add PCB hardware projects and engineering log
2026-10-06 Simplify PCB hardware documentation
2026-10-06 Restore correct H7 PCB project

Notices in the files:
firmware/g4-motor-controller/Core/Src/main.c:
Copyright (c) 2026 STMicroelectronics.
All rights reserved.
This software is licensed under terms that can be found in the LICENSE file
